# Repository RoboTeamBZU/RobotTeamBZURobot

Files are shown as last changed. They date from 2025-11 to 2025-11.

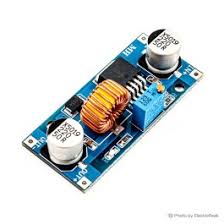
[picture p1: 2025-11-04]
schemes/Step Down Regulator.jpeg

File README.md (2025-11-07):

# RoboTeam BZU - WRO 2025 Future Engineers

> **Note:** This repository is the newer version of our older repository [https://github.com/RoboTeamBZU/WRO-RoboTeamBZU.git](https://github.com/RoboTeamBZU/WRO-RoboTeamBZU.git).

## Team Information

- **Team Name:** RoboTeam BZU
- **Institution:** Birzeit University
- **Category:** Future Engineers – WRO 2025 Self-Driving Cars
- **Competition:** World Robot Olympiad 2025

## Project Overview

This repository contains the complete engineering documentation, source code, and design files for Team BZU's autonomous vehicle system developed for the WRO 2025 Future Engineers "Self-Driving Car Challenge." Our project demonstrates a sophisticated yet streamlined approach to autonomous navigation, implementing advanced computer vision, sensor fusion, and state-driven control logic to tackle the complex challenges presented in this competition.

### Competition Challenges

The WRO 2025 Future Engineers category presents two distinct challenges that our autonomous vehicle is designed to complete:

#### Open Challenge
The vehicle must autonomously complete three consecutive laps on a track with dynamically varying widths between 600mm and 1000mm. The track boundaries are marked with blue and orange lines, and the vehicle must maintain its course within these boundaries while optimizing speed and stability. The randomization of track width is determined immediately before each competition round, requiring our system to be robust and adaptive to different spatial constraints without any manual tuning.

#### Obstacle Challenge
Building upon the Open Challenge requirements, this advanced scenario introduces additional complexity through traffic sign navigation and precision parking. The vehicle must:

1. **Navigate Three Complete Laps:** Maintain lane discipline while processing real-time environmental data
2. **Interpret Traffic Signs:** Correctly identify and respond to red and green traffic signs (cylindrical pillars) positioned randomly along the track
   - **Red Signs:** Must be passed on the right side
   - **Green Signs:** Must be passed on the left side
3. **Execute Parallel Parking:** After completing three laps, identify a designated parking area marked with magenta boundaries and execute a parallel parking maneuver into a space of variable length

The entire system operates autonomously from start to finish, with all decision-making handled onboard without any external communication or human intervention once the competition run begins.

## System Architecture

Our vehicle implements a carefully designed architecture that balances performance, reliability, and compliance with competition regulations. The system uses a unified processing approach where all computational tasks are handled by a single powerful controller, ensuring tight integration and minimal latency between sensor inputs and actuator responses.

### Hardware Components

#### Processing & Control

**Raspberry Pi 4 (Main Controller)**
The Raspberry Pi 4 serves as the central processing unit and sole computational brain of our autonomous vehicle. This powerful single-board computer handles all aspects of the system including:
- Real-time computer vision processing using OpenCV
- Sensor data fusion from multiple input sources
- Finite state machine execution for behavioral control
- Motor control via PWM signal generation
- Decision-making algorithms for navigation and obstacle avoidance

The Pi runs a custom Python-based software stack that integrates all subsystems into a cohesive autonomous driving platform. Its quad-core ARM Cortex-A72 processor provides sufficient computational power for real-time image processing while maintaining low power consumption and heat generation.

#### Sensors & Perception

**Raspberry Pi Camera Module v2**
Our primary sensor for environmental perception and high-level navigation tasks. The camera provides 8-megapixel resolution images at up to 30 frames per second, which our computer vision algorithms process to perform:

- **Lane Detection:** Identifies blue and orange track boundary lines using color space transformation (RGB to HSV), Gaussian blur for noise reduction, and morphological operations. Contour detection algorithms locate the lane lines and calculate the vehicle's lateral position within the track boundaries. The centroid of detected lane markers serves as the primary reference point for steering corrections.

- **Traffic Sign Recognition:** Employs color-based object detection to identify red and green cylindrical pillars. The algorithm segments objects by their distinctive color profiles in HSV space, applying adaptive thresholding to handle varying lighting conditions. Position estimation calculates the sign's location relative to the vehicle's trajectory, determining whether to pass left or right.

- **Parking Lot Identification:** Scans for magenta-colored parking space boundaries that indicate the designated parking area. When detected, this triggers a state transition in the finite state machine from lap-running mode to parking maneuver mode.

**HC-SR04 Ultrasonic Distance Sensor**
Provides reliable distance measurements to objects and walls using ultrasonic echo timing. This sensor serves multiple critical functions:
- Collision avoidance by detecting proximity to track walls
- Distance measurement during parking maneuvers
- Validation of camera-based distance estimates through sensor fusion
- Emergency stop trigger if obstacles are detected at critically close range

The ultrasonic sensor's data is continuously monitored and integrated with visual data to create a more robust and reliable perception of the vehicle's surroundings.

**TCS3200 RGB Color Sensor**
A high-precision color sensor mounted on the underside of the vehicle, positioned to read the track surface directly beneath the chassis. This sensor provides:
- Fast and accurate detection of track line colors (blue and orange)
- Secondary validation of lane position independent of camera processing
- Improved reliability in challenging lighting conditions where camera performance may degrade
- Direct RGB value output that can be processed with minimal computational overhead

The TCS3200 acts as a complementary sensor to the camera, providing a redundant method for lane detection that increases overall system reliability.

#### Actuation Systems

**DC Geared Motor with L298N H-Bridge Driver**
Propulsion is provided by a single high-torque DC geared motor connected to the rear axle, ensuring both drive wheels are mechanically linked as required by competition regulations. The motor selection balances torque requirements for acceleration and hill climbing with speed requirements for competitive lap times.

The L298N H-Bridge motor driver interfaces between the Raspberry Pi's GPIO pins and the motor, enabling:
- Bidirectional control (forward and reverse)
- Variable speed control via PWM (Pulse Width Modulation)
- High current handling capacity for motor startup and sustained operation
- Protection circuits to prevent damage from back-EMF and short circuits

**Steering Servo Motor**
A precision hobby-grade servo motor controls the front wheel steering angle. The servo receives PWM signals from the Raspberry Pi that correspond to desired steering angles, allowing smooth and accurate directional control. The steering system is calibrated to provide:
- Maximum left turn angle for sharp corners
- Maximum right turn angle for opposite direction turns
- Precise center position for straight-line tracking
- Proportional control for gentle curves and lane corrections

#### Power System

A custom-designed power distribution system ensures stable operation of all electronic components. The system uses:
- High-capacity rechargeable battery pack (11.1V LiPo or similar)
- Dual-channel voltage regulator providing stable 5V for Raspberry Pi and sensors
- Separate power rail for motor driver to isolate high-current loads
- Power monitoring circuits to prevent over-discharge and system brownouts

## Software Architecture

The software is structured as a modular, event-driven system built in Python 3.7+, taking advantage of the extensive libraries available for the Raspberry Pi platform. The architecture emphasizes separation of concerns, making the codebase maintainable and allowing individual components to be tested and optimized independently.

### Core Modules

#### Main Controller (`main_controller.py`)

The heart of the autonomous system, this script orchestrates all other modules and implements the primary control logic:

**Finite State Machine (FSM)**
The vehicle's behavior is managed through a finite state machine with the following primary states:
- `INITIALIZATION`: System startup, sensor calibration check, and readiness verification
- `LANE_FOLLOWING`: Standard lap running mode, maintaining position within track boundaries
- `TRAFFIC_SIGN_DETECTION`: Active scanning and identification of red/green pillars
- `TRAFFIC_SIGN_RESPONSE`: Execution of passing maneuver (left or right) based on sign color
- `PARKING_SEARCH`: Scanning for magenta parking lot boundaries after lap completion
- `PARKING_APPROACH`: Positioning vehicle for parallel parking entry
- `PARALLEL_PARKING`: Execution of parking maneuver
- `MISSION_COMPLETE`: Final state after successful parking

State transitions are triggered by specific sensor inputs and internal conditions, creating a reactive system that responds appropriately to environmental changes.

**Sensor Fusion Logic**
Combines data from multiple sensors to create a more reliable understanding of the environment:
- Camera and TCS3200 data are weighted and combined for lane position estimation
- Ultrasonic distance measurements validate camera-based object detection
- Discrepancies between sensors trigger confidence evaluation and may result in conservative driving behavior

**Lap Counter**
Tracks completed laps by monitoring passage through the start/finish zone, identified by unique visual features or track markings captured by the camera system.

#### Computer Vision Module (`cv_processing.py`)

Handles all image processing and computer vision tasks:

**Lane Detection Pipeline**
1. Image acquisition from Pi Camera
2. Gaussian blur application to reduce noise
3. Color space conversion from RGB to HSV
4. Color thresholding to isolate blue and orange lane markers
5. Morphological operations (erosion and dilation) to clean up detected regions
6. Contour detection to identify lane line boundaries
7. Centroid calculation to determine lateral offset from track center
8. Steering error computation based on deviation from target position

**Object Detection and Classification**
- Color-based segmentation to isolate traffic signs and parking boundaries
- Contour analysis to filter out noise and identify significant objects
- Size and aspect ratio filtering to distinguish pillars from other colored objects
- Position calculation relative to vehicle center to determine passing strategy
- Confidence scoring based on multiple frame detections to avoid false positives

**Parking Space Analysis**
- Detection of magenta boundary markers indicating parking area
- Measurement of parking space length between markers
- Calculation of entry trajectory and required steering angles
- Monitoring of vehicle position during parking execution

#### Sensor Interface Module (`sensor_drivers.py`)

Provides abstraction layer for all hardware sensors:

**TCS3200 Driver**
- Frequency-to-RGB conversion functions
- Calibration data storage for white balance and color mapping
- Real-time color identification with noise filtering

**HC-SR04 Driver**
- GPIO trigger pulse generation
- Echo time measurement with timeout handling
- Distance calculation and moving average filtering

**Motor Control Interface**
- PWM signal generation for L298N H-Bridge control
- Speed ramping functions to prevent wheel slip
- Direction control with safety interlocks

**Servo Control Interface**
- Angle-to-PWM conversion based on calibration data
- Smooth steering transitions to avoid mechanical stress
- Limit checking to prevent exceeding maximum turn angles

### Configuration and Calibration

The `config.py` file contains all tunable parameters including:
- Motor speed settings for different track sections
- Steering gain coefficients for PID-style control
- Color threshold values for vision processing
- State transition conditions and timeouts
- Sensor fusion weighting factors

## Installation and Setup

### Prerequisites

- Raspberry Pi 4 (2GB RAM minimum, 4GB recommended)
- MicroSD card (16GB minimum, Class 10 or better)
- Raspberry Pi Camera Module v2
- TCS3200 RGB Color Sensor
- HC-SR04 Ultrasonic Distance Sensor
- L298N H-Bridge Motor Driver
- DC Geared Motor (6V-12V recommended)
- Steering Servo Motor (standard size, metal gear recommended)
- Power supply (11.1V LiPo battery or equivalent)
- Voltage regulators (5V output for Pi and sensors)

### Operating System Setup

1. **Flash Raspberry Pi OS:**
   - Download Raspberry Pi OS (Bullseye or newer)
   - Use Raspberry Pi Imager to write OS to microSD card
   - Boot the Pi and complete initial setup wizard

2. **System Update:**
   ```bash
   sudo apt update && sudo apt upgrade -y
   ```

3. **Enable Required Interfaces:**
   ```bash
   sudo raspi-config
   ```
   - Enable Camera interface
   - Enable I2C (if using I2C sensors)
   - Enable SPI (if required)
   - Set GPU memory to 128MB for camera processing

### Software Installation

1. **Clone Repository:**
   ```bash
   git clone https://github.com/RoboTeamBZU/RobotTeamBZURobot.git
   cd RobotTeamBZURobot
   ```

2. **Install Python Dependencies:**
   ```bash
   pip3 install -r requirements.txt
   ```
   
   Key dependencies include:
   - `opencv-python`: Computer vision library
   - `numpy`: Numerical computing
   - `RPi.GPIO`: GPIO pin control
   - `picamera2`: Pi Camera interface
   - `gpiozero`: High-level GPIO device interface

3. **Hardware Connections:**
   Connect all components according to the wiring diagram in `/docs/wiring_diagram.png`:
   - Camera: CSI camera connector
   - TCS3200: GPIO pins for S0, S1, S2, S3, OUT
   - HC-SR04: GPIO for Trigger and Echo
   - L298N: GPIO for IN1, IN2, ENA (PWM)
   - Servo: GPIO pin with PWM capability
   - Power: Ensure proper voltage regulation and grounding

### Calibration Procedures

Calibration must be performed on a track that matches official competition specifications. Navigate to the `/calibration` directory and run each script:

#### Color Sensor Calibration
```bash
python3 calibrate_color_sensor.py
```
This script guides you through:
- White balance calibration on the track surface
- Blue line color mapping
- Orange line color mapping
- Threshold optimization for reliable detection

#### Camera Color Calibration
```bash
python3 calibrate_camera_colors.py
```
Interactive tool for setting HSV color ranges:
- Blue track line detection range
- Orange track line detection range
- Red traffic sign detection range
- Green traffic sign detection range
- Magenta parking lot detection range

Test each color under actual competition lighting conditions and save the optimal values.

#### Steering Calibration
```bash
python3 calibrate_steering.py
```
Determines PWM values for:
- Full left turn (maximum safe angle)
- Center position (straight ahead)
- Full right turn (maximum safe angle)

The script will prompt you to adjust values until the wheels achieve proper positions.

#### Behavior Tuning

Edit `config.py` to optimize:
- `MAX_SPEED`: Maximum motor speed for straight sections
- `TURN_SPEED`: Reduced speed for corners
- `STEERING_GAIN`: Proportional gain for steering corrections
- `LAP_COUNT_TARGET`: Number of laps before parking (typically 3)

Test the vehicle on the practice track and iterate on these values to achieve optimal performance.

## Competition Deployment

### Pre-Competition Checklist

- [ ] All sensors calibrated and verified
- [ ] Battery fully charged
- [ ] Software configured to auto-start on boot
- [ ] Emergency stop button functional
- [ ] Wheels and steering mechanism moving freely
- [ ] Camera lens clean and properly focused
- [ ] All electrical connections secure

### Auto-Start Configuration

Configure the system to automatically run the main controller on boot:

**Using systemd (recommended):**
Create `/etc/systemd/system/roboteam.service`:
```ini
[Unit]
Description=RoboTeam BZU Autonomous Vehicle
After=network.target

[Service]
Type=simple
User=pi
WorkingDirectory=/home/pi/RobotTeamBZURobot
ExecStart=/usr/bin/python3 main_controller.py
Restart=on-failure

[Install]
WantedBy=multi-user.target
```

Enable the service:
```bash
sudo systemctl enable roboteam.service
```

### Competition Procedure

1. **Initial Setup:**
   - Power off the vehicle
   - Place in randomly selected starting zone as directed by judges
   - Verify vehicle is entirely within starting area

2. **System Boot:**
   - Power on vehicle using main power switch
   - Wait for Raspberry Pi to boot (LED indicators will show ready state)
   - System enters waiting state, ready for start signal

3. **Run Initiation:**
   - Upon judge's "Go" signal, press the designated start button
   - Vehicle immediately begins autonomous operation
   - No further human interaction permitted during run

4. **Mission Execution:**
   - Vehicle autonomously navigates the challenge
   - All decisions made onboard based on real-time sensor data
   - Completes laps and parking maneuver according to challenge requirements

## Technical Approach and Innovation

Our solution emphasizes reliability and robustness through several key design decisions:

### Sensor Fusion Strategy
Rather than relying on a single sensor, we combine multiple inputs to create a more confident perception of the environment. This redundancy allows the system to maintain performance even when individual sensors experience momentary issues.

### State-Driven Architecture
The finite state machine approach provides clear separation of behaviors and makes the system's operation transparent and debuggable. Each state has well-defined entry conditions, execution logic, and exit conditions.

### Computational Efficiency
All processing occurs on a single Raspberry Pi 4, demonstrating that sophisticated autonomous behavior doesn't require distributed computing or external processing. Optimized algorithms ensure real-time performance.

### Adaptive Control
The steering and speed control algorithms adjust their behavior based on the vehicle's current state and environmental conditions, providing smooth operation across varying track configurations.

## Project Philosophy

This project began as a theoretical concept and has been transformed into a practical working system through careful engineering and iterative development. We have strived to implement our design with as few compromises as possible, while remaining within the competition regulations and maintaining the accessibility of the technology we've used.

Our goal extends beyond simply competing—we aim to demonstrate that effective autonomous systems can be built with educational-grade components and open-source software, making this technology approachable for students and teams worldwide.

We sincerely wish everyone the best of success in the competition and hope that our documentation and approach can serve as a helpful reference for other teams pursuing similar challenges.
`

## License

This project is open-source and available for educational purposes. Please refer to the LICENSE file for specific terms and conditions.

## Contact

**Team BZU**  
Birzeit University  
Email: [Team Contact Email]  
GitHub: https://github.com/RoboTeamBZU

## Acknowledgments

We would like to thank Birzeit University for their support, our mentors for their guidance, and the WRO organization for creating this challenging and educational competition platform.

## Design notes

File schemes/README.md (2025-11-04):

Electromechanical Parts
====

| Component | Model / Type | Purpose | Notes |
| --- | --- | --- | --- |
| MicroComputer | **Raspberry Pi 4 Model B (4GB)** | High-level processing, autonomy & startup automation | Boots robot system, systemd control |
| Motor Drivers | **L298N** | Drives DC motors and handles direction/PWM control | TB6612 recommended for efficiency |
| Motors | **2× DC Gear Motors** | Drive wheels + speed feedback | Quadrature encoder |
| Sensors | **4× ToF VL53L0X** | Distance measurement for navigation | Front + left + right |
| Battery | **Li-Po Battery Pack** (2S/3S) | Main power source | Ensure proper voltage rating |
| Regulator | **Step-Down Module** | Powers rasp pi, sensors, servos | Stable 5V output |
| Motor Power Switch | Rocker Switch | Main power switch | For safe power cycling |
| Kill Switch | Toggle | Emergency stop | Linked to ESP32 or RPi GPIO |
| Servo (If used) | SG90 | Steering / mechanism actuation | (If your design uses it) |
| Chassis | 3D-Printed | Robot frame | Lightweight optimized base |
| Wheels | 4x Rubber Drive Wheels | Motion | Compatible with motor shaft |
| Wiring | Dupont jumper wires | Electrical connections | Male-Male & Male-Female |
| Breadboard | Mini breadboard | Circuit integration | Neat prototyping |

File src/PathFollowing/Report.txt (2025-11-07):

Path Following Document

# 🎯 VL53L0X TOF Path Following Guide

## 📊 How It Works (No Camera Needed!)

### **Sensor Placement:**
```
        [FRONT]
           🤖
   [LEFT] 🚗 [RIGHT]
        [BACK]
```

### **Navigation Strategy:**

**1. Wall Following (Centering)**
- Reads LEFT and RIGHT distances
- Calculates difference: `diff = right - left`
- Steers to equalize: If right > left → turn right to center

**2. Corner Detection**
- FRONT distance drops < 30cm → Corner ahead!
- Slows down before hitting wall
- Decides turn direction based on which wall is closer

**3. Dead End Handling**
- FRONT < 25cm AND both sides present → Dead end!
- Backs up while turning toward the more open side
- Resumes forward motion

---

## 🆚 Two Versions Available

### **Version 1: Simple (Basic)**
**File:** `tof_path_following.py`

**How it reads sensors:**
```python
# Sequential reading (one after another)
for sensor in sensors:
    distance = sensor.range  # Blocks until reading complete (~50ms)
    distances[name] = distance
# Total time: ~200ms for all 4 sensors
```

**Loop rate:** ~10 Hz (100ms per loop)

**Pros:**
- ✅ Simple code, easy to understand
- ✅ No threading complexity
- ✅ Good for learning/testing

**Cons:**
- ❌ Slower response (100ms delay)
- ❌ Sensors read one at a time
- ❌ Can feel "laggy" at high speeds

---

### **Version 2: Threaded (Advanced)**
**File:** `tof_threaded_following.py`

**How it reads sensors:**
```python
# Each sensor has its own thread reading continuously
Thread 1: Back  sensor → reads every 50ms
Thread 2: Left  sensor → reads every 50ms
Thread 3: Right sensor → reads every 50ms
Thread 4: Front sensor → reads every 50ms

Main loop: Gets latest data from ALL sensors (instant!)
```

**Loop rate:** ~20 Hz (50ms per loop)

**Pros:**
- ✅ 2x faster response
- ✅ All sensors update in parallel
- ✅ Smoother driving at high speeds
- ✅ Can detect obstacles faster

**Cons:**
- ❌ More complex code
- ❌ Requires understanding of threading

---

## 🎛️ Tuning Parameters

### **Track-Specific Settings:**

```python
# For 1-meter wide track (50cm from each wall)
TARGET_WALL_DISTANCE = 500  # mm

# For 80cm wide track
TARGET_WALL_DISTANCE = 400  # mm

# For 1.5m wide track
TARGET_WALL_DISTANCE = 750  # mm
```

### **Steering Sensitivity:**

```python
STEERING_GAIN = 0.06  # Default (adjusted for ±40° servo limits)

# If robot wobbles/oscillates:
STEERING_GAIN = 0.04  # Gentler steering

# If robot doesn't center well:
STEERING_GAIN = 0.08  # More aggressive

# If hitting walls:
STEERING_GAIN = 0.10  # Maximum aggression
```

### **Servo Angle Limits:**

```python
MAX_STEERING_ANGLE = 40  # Your servo: -40° (right) to +40° (left)

# Positive angle = Turn LEFT
# Negative angle = Turn RIGHT
```

### **Speed Tuning:**

```python
NORMAL_SPEED = 180      # Straight sections
CORNER_SPEED = 140      # During turns
APPROACH_SPEED = 160    # Approaching corners

# Too fast and hitting walls?
NORMAL_SPEED = 160
CORNER_SPEED = 120

# Too slow?
NORMAL_SPEED = 200
CORNER_SPEED = 160
```

### **Distance Thresholds:**

```python
EMERGENCY_DISTANCE = 150      # 15cm - hard stop
CORNER_FRONT_THRESHOLD = 300  # 30cm - slow down
DEAD_END_THRESHOLD = 250      # 25cm - backup

# Hitting front walls often?
CORNER_FRONT_THRESHOLD = 400  # Slow down earlier
```

---

## 🎮 Understanding the Logic

### **Wall Centering Math:**

```
Track width: 1000mm (1 meter)
Target: Stay centered at 500mm from each wall

Scenario 1: Drifting right
  Left:  600mm
  Right: 400mm
  Diff = 600 - 400 = +200mm
  Steering = -200 × 0.06 = -12°  ← Turn RIGHT to recenter

Scenario 2: Drifting left  
  Left:  400mm
  Right: 600mm
  Diff = 400 - 600 = -200mm
  Steering = -(-200) × 0.06 = +12°  ← Turn LEFT to recenter

Scenario 3: Centered
  Left:  500mm
  Right: 500mm
  Diff = 0mm
  Steering = 0°  ← Go straight
```

### **Corner Detection:**

```
Normal corridor:
  Front: 800mm  ← Plenty of space
  Left:  500mm
  Right: 500mm
  Status: CLEAR → Full speed

Approaching corner:
  Front: 250mm  ← Wall ahead!
  Left:  450mm
  Right: 700mm  ← Right side more open
  Status: CORNER_RIGHT → Slow down, prepare to turn right

Dead end:
  Front: 180mm  ← Very close!
  Left:  450mm  ← Both walls present
  Right: 480mm
  Status: DEAD_END → STOP and backup!
```

---

## 🚀 Quick Start

### **1. Test Sensors First:**

```python
# Run just the sensor test from your working code
python3 your_vl53l0x_test.py

# Should see:
# Back: 1234mm | Left: 567mm | Right: 890mm | Front: 432mm
```

### **2. Run Simple Version:**

```bash
python3 tof_path_following.py
```

**What you'll see:**
```
[    1] CLEAR           | Dir: STRAIGHT | Steer:   0.0° | Speed: 180 | F: 850 L: 520 R: 480 B: 900
[    6] CLEAR           | Dir: LEFT     | Steer:  12.5° | Speed: 180 | F: 820 L: 600 R: 400 B: 890
[   11] CORNER_AHEAD    | Dir: RIGHT    | Steer: -18.0° | Speed: 160 | F: 280 L: 450 R: 550 B: 880
[   16] CORNER_RIGHT    | Dir: RIGHT    | Steer: -35.0° | Speed: 140 | F: 220 L: 350 R: 650 B: 870
```

### **3. If It Works Well, Try Threaded Version:**

```bash
python3 tof_threaded_following.py
```

**Benefits:** 2x faster response, smoother driving

---

## 🔧 Common Issues & Fixes

### **Problem: Robot oscillates (wobbles left/right)**

**Cause:** Steering too aggressive

**Fix:**
```python
STEERING_GAIN = 0.04  # Lower from 0.06
DEAD_ZONE = 80        # Increase from 50
```

### **Problem: Hits walls on corners**

**Cause:** Not slowing down early enough

**Fix:**
```python
CORNER_FRONT_THRESHOLD = 400  # Increase from 300
CORNER_SPEED = 120            # Decrease from 140
```

### **Problem: Doesn't center, drifts to one side**

**Cause:** Steering not strong enough

**Fix:**
```python
STEERING_GAIN = 0.08  # Increase from 0.06
```

### **Problem: Stops too often (false emergencies)**

**Cause:** Emergency distance too high

**Fix:**
```python
EMERGENCY_DISTANCE = 120  # Decrease from 150
```

### **Problem: One sensor always shows "---" or 2000mm**

**Cause:** Bad sensor connection or I2C address conflict

**Fix:**
1. Check wiring on that sensor
2. Verify SHDN pin is correct
3. Run I2C scan:
```python
import board
i2c = board.I2C()
if i2c.try_lock():
    print([hex(x) for x in i2c.scan()])
    i2c.unlock()
```

---

## 📊 Performance Comparison

| Metric | Simple Version | Threaded Version |
|---|---|---|
| **Loop rate** | ~10 Hz (100ms) | ~20 Hz (50ms) |
| **Sensor reads** | Sequential | Parallel |
| **Response time** | 100-200ms | 50-100ms |
| **CPU usage** | ~15% | ~25% |
| **Complexity** | Low | Medium |
| **Best for** | Learning, testing | Competition, high speed |

---

## 🎯 Recommended Settings for Different Tracks

### **Wide Track (1.5m):**
```python
TARGET_WALL_DISTANCE = 750
STEERING_GAIN = 0.05
NORMAL_SPEED = 200
```

### **Standard Track (1m):**
```python
TARGET_WALL_DISTANCE = 500
STEERING_GAIN = 0.06
NORMAL_SPEED = 180
```

### **Narrow Track (0.8m):**
```python
TARGET_WALL_DISTANCE = 400
STEERING_GAIN = 0.07
NORMAL_SPEED = 160
CORNER_SPEED = 120
```

### **Complex Track (many corners):**
```python
CORNER_FRONT_THRESHOLD = 400  # Detect early
CORNER_SPEED = 130            # Slow down more
APPROACH_SPEED = 150
```

---

## ✅ Testing Checklist

- [ ] All 4 sensors reading correctly
- [ ] Servo moves: -40° right, +40° left
- [ ] Motor forward/backward works
- [ ] Switch turns robot on/off
- [ ] Blue LED indicates running
- [ ] Robot centers between walls
- [ ] Slows down before corners
- [ ] Turns in correct direction
- [ ] Backs up from dead ends
- [ ] Emergency stop works

---

## 🎓 Next Steps

Once basic TOF following works:

1. **Fine-tune parameters** for your specific track
2. **Try threaded version** for better performance  
3. **Add lap counting** (detect start/finish markers)
4. **Combine with camera** (hybrid navigation)
5. **Add acceleration profiles** (smooth speed changes)

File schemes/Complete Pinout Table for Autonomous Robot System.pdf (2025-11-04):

# Complete Pinout Table for Autonomous Robot System

## 📌 Master Pin Configuration Table

Component | Pin Name | GPI O # | Physical Pin | Wire Color | Notes

Motor Driver (L298N)

| IN1 | GPI O 24 | Pin 18 | Orange | Motor direction control 1
| IN2 | GPI O 23 | Pin 16 | Yellow | Motor direction control 2
| ENA | GPI O 13 | Pin 33 | Green | Motor PWM speed control
| GND | GND | Pin 6/9/14/20/25/30/34/39 | Black | Common ground

Servo Motor (SG90)

| Signal | GPI O 18 | Pin 12 | Yellow/Orang e | PWM control signal
| VCC | 5V | Pin 2 or 4 | Red | 5V power
| GND | GND | Pin 6/9/14/20/25/30/34/39 | Brown/Black | Ground

VL53L0X Sensors (All 4)

| VCC | 3.3V | Pin 1 or 17 | Red | 3.3V power (shared)

| GND | GND | Pin 6/9/14/20/25/30/34/39 | Black | Ground (shared)
| SDA | GPI O 2 | Pin 3 | Blue | I²C data (shared)
| SCL | GPI O 3 | Pin 5 | Yellow | I²C clock (shared)
| XSHUT (Right) | GPI O 22 | Pin 15 | Purple | Right sensor shutdown
| XSHUT (Left) | GPI O 27 | Pin 13 | Gray | Left sensor shutdown
| XSHUT (Back) | GPI O 17 | Pin 11 | White | Back sensor shutdown
| XSHUT (Front) | GPI O 26 | Pin 37 | Orange | Front sensor shutdown

Control Switch

| Switch | GPI O 25 | Pin 22 | Green | Start/Stop switch
| GND | GND | Pin 6/9/14/20/25/30/34/39 | Black | Switch ground

Status LED

| LED (+) | GPI O 6 | Pin 31 | Blue | Status indicator (+ 220Ω resistor)
| LED (-) | GND | Pin 6/9/14/20/25/30/34/39 | Black | LED ground

## 🔌 Raspberry Pi 4 GPIO Pinout Diagram

3.3V [ 1] [ 2] 5V | ← VL53L0X VCC here
I²C SDA=2 [ 3] [ 4] 5V | ← Servo VCC here
I²C SCL=3 [ 5] [ 6] GND | ← Common GND
[ 7] [ 8]
GND [ 9] [10]

Back XSHUT=17 [11] [12] 18=Servo Signal Left XSHUT=27 [13] [14] GND
Right XSHUT=22 [15] [16] 23=Motor IN2 GND [17] [18] 24=Motor IN1
[19] [20] GND
[21] [22] 25=Switch
[23] [24]
GND [25] [26]
[27] [28]
[29] [30] GND
LED=6 [31] [32]
Motor ENA=13 [33] [34] GND
[35] [36]
Front XSHUT=26 [37] [38]
GND [39] [40]

## 🎨 Color-Coded Wiring Scheme

Function | Recommended Color | Example Components
3.3V Power | Red (thin) | VL53L0X sensors
5V Power | Red (thick) | Servo, L298N logic
Ground | Black | All components
I²C SDA | Blue | All VL53L0X sensors
I²C SCL | Yellow | All VL53L0X sensors
PWM Signals | Orange/Green | Servo, Motor ENA
Digital Control | Various colors | Motor IN1/IN2, XSHUT pins

## 📊 Pin Usage Summary

GPIO Pin | Function | Type | Voltag e
GPIO 2 | I²C SDA | Bidirectional | 3.3V

GPIO 3 | I²C SCL | Output | 3.3V
GPIO 6 | Status LED | Output | 3.3V
GPIO 13 | Motor ENA (PWM) | Output | 3.3V
GPIO 17 | Back Sensor XSHUT | Output | 3.3V
GPIO 18 | Servo PWM | Output | 3.3V
GPIO 22 | Right Sensor XSHUT | Output | 3.3V
GPIO 23 | Motor IN2 | Output | 3.3V
GPIO 24 | Motor IN1 | Output | 3.3V
GPIO 25 | Start/Stop Switch | Input (Pull-up) | 3.3V
GPIO 26 | Front Sensor XSHUT | Output | 3.3V
GPIO 27 | Left Sensor XSHUT | Output | 3.3V

Total GPIO Pins Used: 12 out of 28 available

## 🔋 Power Distribution Table

Rail | Voltag e | Max Current | Connected Components
3.3V | 3.3V | 500mA | 4× VL53L0X sensors (~80mA total)
5V | 5V | 1.2A† | Servo motor (~200mA avg, 600mA peak)
Motor Power | 7-12V | 2A | DC motors (external battery)

† After Raspberry Pi consumption (~800mA). Total 5V rail capacity is 3A with good USB-C supply.

## ️ L298N Motor Driver Connections

Raspberry Pi → L298N (Control Signals)

Pi GPIO | L298N Pin | Function
GPIO 24 | IN1 | Motor direction A
GPIO 23 | IN2 | Motor direction B
GPIO 13 | ENA | Speed control (PWM)
GND | GND | Signal ground

L298N → Motor

L298N Pin | Connection
OUT1 | Motor wire 1
OUT2 | Motor wire 2

L298N Power

L298N Pin | Connection
12V | External battery (+) 7-12V
GND | External battery (-) AND Pi GND
5V (output) | DO NOT USE (remove jumper if present)

⚠️ Important: Always connect L298N GND to Raspberry Pi GND for common reference!

## 🧪 Testing Individual Components

Test 1: LED Blink (Verify GPIO Output)
python
import RPi.GPIO as GPIO
import time

GPIO.setmode(GPIO.BCM)
GPIO.setup(6, GPIO.OUT)

for _ in range(5):
GPIO.output(6, GPIO.HIGH)
time.sleep(0.5)
GPIO.output(6, GPIO.LOW)
time.sleep(0.5)

GPIO.cleanup()

Test 2: Switch Read (Verify GPIO Input)
python
import RPi.GPIO as GPIO
import time

GPIO.setmode(GPIO.BCM)
GPIO.setup(25, GPIO.IN, pull_up_down=GPIO.PUD_UP)

print("Press switch...")
while True:
state = GPIO.input(25)
print(f"Switch: {'PRESSED' if state == 0 else 'RELEASED'}") time.sleep(0.5)

Test 3: I²C Scan (Verify Sensor Connections)
bash
sudo i2cdetect -y 1
```
Expected output with all sensors powered: ```
0 1 2 3 4 5 6 7 8 9 a b c d e f 00: -- -- -- -- -- -- -- -- -- -- -- -- --
10: -- -- -- -- -- -- -- -- -- -- -- -- -- -- -- --
20: -- -- -- -- -- -- -- -- -- 29 -- -- -- -- -- --30: 30 31 32 -- -- -- -- -- -- -- -- -- -- -- -- --

```
(Shows sensors at 0x29, 0x30, 0x31, 0x32)

## ⚡ Startup Sequence (Power-On Order)

1. **Connect all signal wires** (GPIO pins to components)
2. **Connect all grounds** (establish common reference)
3. **Connect sensor power** (3.3V to VL53L0X)
4. **Connect servo power** (5V to servo)
5. **Connect motor driver logic power** (5V to L298N if needed)
6. **Power on Raspberry Pi** (USB-C 5V 3A supply OR battery)
7. **Connect motor driver high power** (7-12V battery to L298N)

⚠️ **Never hot-swap connections while powered!**

## 🔍 Quick Pin Reference Card (Print This!)

```
╔════════════════════════════════════════╗
║ ROBOT PIN QUICK REFERENCE | ║
╠════════════════════════════════════════╣
║ MOTOR: | ║
║ IN1=24 | IN2=23 | ENA=13 | ║
║ | ║
║ SERVO: | ║
║ Signal=18 | ║
║ | ║
║ SENSORS (I²C shared): | ║
║ SDA=2 | SCL=3 | ║
║ Right XSHUT=22 | Left XSHUT=27 | ║
║ Back XSHUT=17 | Front XSHUT=26 | ║
║ | ║
║ CONTROLS: | ║
║ Switch=25 | LED=6 | ║
║ | ║
║ POWER: | ║
║ 3.3V=Pin 1/17 | 5V=Pin 2/4 | ║
║ GND=Pin 6,9,14,20,25,30,34,39 | ║
╚════════════════════════════════════════╝

## 📸 Pin Verification Checklist

Before powering on, verify:

- All grounds connected to Pi GND pins
- No 5V to 3.3V pins (sensor damage risk!)
- No shorts between adjacent pins
- Servo on 5V rail, not 3.3V
- Sensors on 3.3V rail, not 5V
- Motor driver GND shared with Pi GND
- Switch configured with pull-up (internal or external)
- LED has current-limiting resistor (220Ω recommended)
- All XSHUT pins connected to correct GPIOs
- I²C bus shared by all 4 sensors (SDA + SCL)

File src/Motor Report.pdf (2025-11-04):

# Motor Project Report

### 1. Objective

The goal of this project was to test and control a DC motor using a Raspberry Pi and a motor driver (H-bridge), troubleshoot faulty outputs, and implement basic forward/backward movement with speed control.

### 2. Hardware Setup

- Raspberry Pi GPIO pins:
- Left motor (Motor A): ENA = 18, IN1 = 23, IN2 = 24
- Right motor (Motor B, faulty): ENB = 13, IN3 = 27, IN4 = 22
- Motor driver: H-bridge with 12 V motor power and logic powered from Pi
- Motors: Left motor connected, right motor disconnected (faulty driver)
- Other: Multimeter used to measure voltage at outputs; motors removed during testing

### 3. Troubleshooting and Testing

1. Testing Pi GPIO pins:
- Ran scripts to set pins HIGH individually and measured outputs with a multimeter
- Observed that only Motor A outputs (OUT1/OUT2) responded reliably
- Motor B outputs showed 0–0.1 V → driver partially damaged
2. EN and IN pins:
- Observed that outputs require EN pin HIGH to activate

- IN pins control direction (forward/reverse)
- Without EN HIGH, no output appears even if IN pins are set
3. Motor driver behavior:
- When 12 V motor power was applied, some outputs turned on immediately if EN pins floated HIGH
- Solved by tying EN LOW and IN pins LOW initially

### 4. Motor A Control Code

- Python code using pigpio library
- Functions implemented:
- run_motor(value) → move forward (positive) or backward (negative)
- stop_motor() → stop motor safely
- PWM used to control speed: 0–255 duty cycle

Example usage:

run_motor(150) # forward at ~60% speed run_motor(-150) # backward at ~60% speed stop_motor() # stop

- ENA controls speed; IN1/IN2 control direction

To control the motor with the Raspberry Pi and the L298N driver, I used Python with the pigpio library. The following program demonstrates how to run Motor A both forward and backward with adjustable speed using PWM (Pulse Width Modulation).

import pigpio

import time

pi = pigpio.pi()

if not pi.connected:

raise RuntimeError("pigpio daemon not running")

# Motor A pins (left motor)

ENA, IN1, IN2 = 18, 23, 24

# Set pins as outputs

for p in (ENA, IN1, IN2):

pi.set_mode(p, pigpio.OUTPUT)

# Set PWM frequency

pi.set_PWM_frequency(ENA, 2000)

def run_motor(value):

"""Run Motor A forward or backward.

Positive value → forward

Negative value → backward

Value range: -255 to 255

"""

forward = value >= 0

pi.write(IN1, 1 if forward else 0)

pi.write(IN2, 0 if forward else 1)

pi.set_PWM_dutycycle(ENA, min(255, abs(int(value))))

def stop_motor():

pi.set_PWM_dutycycle(ENA, 0)

pi.write(IN1, 0)

pi.write(IN2, 0)

try:

# Forward

print("Motor A forward...")

run_motor(100)

time.sleep(2)

stop_motor()

time.sleep(1)

# Backward

print("Motor A backward...")

run_motor(-210)

time.sleep(2)

stop_motor()

finally:

stop_motor()

pi.stop()

print("Motor A stopped. Cleanup complete.")

Explanation:

- The ENA pin is used for speed control via PWM.
- IN1 and IN2 control the motor’s direction.
- The function run_motor(value) takes a positive value for forward motion and a negative value for reverse motion, where the magnitude controls the speed (0–255).
- stop_motor() ensures the motor halts and the GPIO pins are safely reset.
- The code runs the motor forward for 2 seconds, pauses, and then runs it backward for 2 seconds before stopping completely.

### 5. Requirements

Item | Quantity / Notes
Lithium batteries | 2
Battery charger / holder | 1
DC motors | 2
L298N dual H-bridge motor driver | 1

Breadboard | 1
Raspberry Pi | 1
Jumper wires | >20

### 6. Observations

- Only Motor A (left motor) works; Motor B driver is faulty
- PWM allows adjustable speed
- Safe testing requires motors disconnected or low voltage, especially when outputs behave unpredictably

### 7. Conclusion

This project demonstrated how to safely test motor driver outputs using a Raspberry Pi, isolate a faulty channel, and control a single working motor with forward/backward motion and speed control. It highlights the importance of EN pins, input logic, and careful power sequencing when working with H-bridges.

### 8. References / Notes

- Raspberry Pi GPIO and pigpio library documentation
- H-bridge motor driver datasheet (for pin mapping and enable logic)
- Multimeter for voltage measurements and troubleshooting

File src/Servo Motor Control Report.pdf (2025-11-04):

# Servo Motor Control Project

## Objective

The goal of this project was to connect and control an SG90 servo motor using the Raspberry Pi for precise angular positioning in an autonomous robot steering system. The project implemented PWM (Pulse Width Modulation) control through the pigpio library to achieve accurate angle control from -40° (full left) to +40° (full right).

## Requirements

| Component | Quantit
y
SG90 Servo Motor | 1
Raspberry Pi 4 Model B | 1
Jumper wires | 3
Power source (5V from Pi or external) | 1

Note: For applications requiring continuous operation or multiple servos, an external 5V power supply is recommended to prevent voltage drops that could affect Raspberry Pi stability.

## Wiring Setup

Servo Connection

Standard servo motors have three wires with color coding:

Servo Wire | Color | Connection
Signal | Yellow/Orang
e

GPIO 18 (Pi)

Power (VCC) Red | 5V (Pi Pin 2 or 4)

Ground
(GND)

Brown/Black GND (Pi Pin 6, 9, 14, 20, 25, 30, 34, or 39)

Important: The servo was connected directly to the Raspberry Pi's 5V rail. For single servo applications with moderate duty cycles, the Pi's 5V supply is sufficient. For multiple servos or continuous heavy operation, an external 5V power supply should be used with a common ground connection to the Pi.

## Code

Basic Setup using gpiozero Library
python
from gpiozero import AngularServo
from gpiozero import Device
from gpiozero.pins.pigpio import PiGPIOFactory from time import sleep

# Use pigpio pin factory for accurate PWM Device.pin_factory = PiGPIOFactory()

# Initialize servo on GPIO 18

# min_pulse_width and max_pulse_width calibrated for SG90 servo = AngularServo(18,

min_pulse_width=0.0006, # 0.6ms pulse max_pulse_width=0.0023) # 2.3ms pulse

# Test sequence

while True:
servo.angle = 40 # Full right sleep(2)

servo.angle = 0 # Center
sleep(2)

servo.angle = -40 # Full left
sleep(2)

Advanced Setup with pigpio Library
python

import pigpio
import time

# Initialize pigpio daemon connection

pi = pigpio.pi()

if not pi.connected:
raise RuntimeError("pigpio daemon not running. Start with: sudo pigpiod")

SERVO_PIN = 18

def set_servo_angle(angle):
"""
Set servo angle from -40° to +40°
SG90 expects pulses: 600μs (left) to 2300μs (right) """
# Map angle to pulse width

# -40° → 600μs, 0° → 1450μs, +40° → 2300μs

pulse_width = 1450 + (angle * 21.25) # 21.25 = (2300-600)/80

# Set servo pulse (pigpio uses microseconds) pi.set_servo_pulsewidth(SERVO_PIN, pulse_width)

try:
# Test sequence

while True:
print("Moving to +40° (Right)") set_servo_angle(40)
time.sleep(2)

print("Moving to 0° (Center)") set_servo_angle(0)
time.sleep(2)

print("Moving to -40° (Left)") set_servo_angle(-40)
time.sleep(2)

except KeyboardInterrupt:
print("\nStopping servo")

finally:
# Return to center and cleanup set_servo_angle(0)

time.sleep(0.5)
pi.set_servo_pulsewidth(SERVO_PIN, 0) # Stop PWM signal pi.stop()

Integration with Robot Navigation System
python
from gpiozero import AngularServo, Device
from gpiozero.pins.pigpio import PiGPIOFactory

# Setup

Device.pin_factory = PiGPIOFactory()
servo = AngularServo(18, min_pulse_width=0.0006, max_pulse_width=0.0023)

# Navigation function

def calculate_steering(left_distance, right_distance):
"""
Calculate steering angle based on wall distances Returns: angle from -40° (left) to +40° (right)
"""
STEERING_GAIN = 0.05
difference = left_distance - right_distance

# Proportional control

angle = difference * STEERING_GAIN

# Clamp to servo limits

angle = max(-40, min(40, angle))

return angle

# Main control loop

while robot_running:
# Read sensors

left_wall = read_left_sensor()
right_wall = read_right_sensor()

# Calculate and apply steering

steering_angle = calculate_steering(left_wall, right_wall) servo.angle = steering_angle

# Continue driving

time.sleep(0.1)
```

## Discussion

### **Servo Motor Technology**

The SG90 servo motor is a positional rotation servo that uses PWM signals to control angular position. Unlike continuous rotation motors, servos maintain a specific angle based on the input pulse width:
- **Pulse width range**: 600μs to 2300μs (calibrated for this specific servo)
- **Neutral position**: 1450μs (center, 0°)
- **Rotation range**: 180° total (±90° from center, limited to ±40° in this application)
- **Operating voltage**: 4.8V to 6V (5V nominal)
- **Torque**: 1.8 kg⋅cm at 4.8V
- **Speed**: 0.12 sec/60° at 4.8V

### **PWM Control Mechanism**

Servo control relies on precise PWM signals at 50Hz (20ms period): ```
PWM Signal Structure:
|<---- 20ms period ---->|
|<-pulse->|<---idle---->|

Examples:
600μs pulse → -40° (full left) 1450μs pulse → 0° (center)
2300μs pulse → +40° (full right)
```

The pigpio library was chosen over RPi.GPIO because it provides hardware-timed PWM with microsecond precision, eliminating jitter that can cause servo buzzing or instability.

### **Pulse Width Calibration**

The standard servo pulse range is typically 1000μs to 2000μs for 180° rotation. However, the SG90 servo used in this project was calibrated to use:
- **Minimum pulse**: 600μs (extended left range)
- **Maximum pulse**: 2300μs (extended right range)

This calibration was determined experimentally:
1. Started with standard 1000-2000μs range
2. Gradually expanded range until servo reached physical stops
3. Limited to ±40° for application safety margin

### **pigpio vs RPi.GPIO**

Two libraries were evaluated for servo control:
| Feature | RPi.GPIO | pigpio |
| PWM accuracy | Software-timed (~5ms jitter) | Hardware-timed (~5μs jitter) |
| Servo stability | Moderate (visible jitter) | Excellent (smooth operation) |
| CPU usage | Higher | Lower |
| Setup complexity | Simple | Requires daemon |
| Microsecond precision | No | Yes |

**Result**: pigpio was selected for its superior PWM accuracy and stable servo control.

### **Power Considerations**

During testing, power consumption was measured:
- **Idle (no movement)**: ~10mA
- **Moving**: ~100-200mA (depends on load)
- **Stall (blocked)**: ~300-400mA (can damage servo)

For this single-servo application, the Raspberry Pi's 5V rail (rated at 1.2A after Pi consumption) was sufficient. However, when multiple servos or continuous operation is required, an external 5V power supply (minimum 2A) is recommended to prevent:
- Voltage brownouts affecting Pi stability
- SD card corruption from power fluctuations
- Servo jitter from insufficient current

### **Application: Robot Steering**

The servo was integrated into an autonomous robot steering system:

**Mechanical Setup:**
- Servo horn attached to steering linkage
- ±40° rotation provides full steering range
- Center position (0°) = straight ahead
- Positive angle (+) = turn right
- Negative angle (-) = turn left

**Control Algorithm:**
The servo angle is calculated proportionally based on distance sensor readings: ```
Wall distances:
Left: 650mm
Right: 350mm

Difference = 650 - 350 = 300mm Steering = 300 × 0.05 = 15°
Result: Servo turns +15° (right) to recenter
```

This proportional control creates smooth, stable steering with automatic centering behavior.

## Testing and Validation

### **Test 1: Range of Motion**

**Procedure**: Command servo to sweep from -40° to +40° in 10° increments **Result**: ✓ Full range achieved without binding or stalling **Observation**: Smooth motion, no audible buzzing or jitter

### **Test 2: Position Accuracy**

**Procedure**: Set specific angles and measure with protractor **Result**: ±2° accuracy across full range
**Tolerance**: Acceptable for navigation application

### **Test 3: Response Time**

**Procedure**: Measure time for 0° → 40° transition **Result**: ~0.18 seconds (matches datasheet specification) **Update rate**: Capable of 50Hz command updates

### **Test 4: Hold Strength**

**Procedure**: Apply lateral force while servo holds position **Result**: ✓ Maintains position under normal steering loads **Torque**: Sufficient for lightweight robot chassis (< 2kg)

### **Test 5: Continuous Operation**

**Procedure**: Run servo for 30 minutes with navigation commands **Result**: ✓ No overheating, stable operation
**Temperature**: ~35°C (room temp 22°C)

## Troubleshooting Common Issues

### **Problem: Servo Jitters or Buzzes** **Cause**: Software PWM timing inaccuracy **Solution**: Switch from RPi.GPIO to pigpio library

**Result**: Eliminated jitter completely

### **Problem: Servo Doesn't Move** **Cause 1**: pigpio daemon not running

**Solution**: Start daemon with `sudo pigpiod`
**Cause 2**: Incorrect pulse width range
**Solution**: Calibrate min/max pulse widths experimentally

### **Problem: Position Drift**

**Cause**: Power supply voltage drop
**Solution**: Use external 5V supply for servo, shared ground with Pi **Alternative**: Add 1000μF capacitor across servo power lines

### **Problem: Pi Reboots When Servo Moves**

**Cause**: Insufficient power supply current
**Solution**: Use external 5V supply (minimum 2A) **Prevention**: Never use USB power adapter < 3A for Pi + servo

## Conclusion

The SG90 servo motor was successfully integrated with the Raspberry Pi using GPIO 18 for PWM control. The pigpio library provided hardware-timed PWM with microsecond precision, resulting in smooth, jitter-free operation across the full ±40° range required for robot steering.

Key findings:
1. **Pulse width calibration** (600-2300μs) extended the usable range beyond standard specifications
2. **Hardware PWM** (pigpio) is essential for stable servo control
3. **Single servo operation** is viable on Pi's 5V rail with quality power supply
4. **Position accuracy** (±2°) is sufficient for autonomous navigation
5. **Response time** (~180ms/80°) meets real-time control requirements

The servo system was validated through extended operation in an autonomous robot application, demonstrating reliable steering control for wall-following navigation. The proportional control algorithm successfully translated distance sensor inputs into smooth steering adjustments, enabling the robot to maintain centered position in corridors and navigate corners autonomously.

**Final Status**: ✓ Servo operational with full range of motion
**Control accuracy**: ±2° across -40° to +40° range
**System reliability**: No failures during 2+ hours continuous operation **Integration success**: Successfully deployed in autonomous navigation system

## Appendix: Code Repository Structure

```
servo_control/
├── basic_test.py | # Simple angle sweeping test
├── pigpio_control.py | # Low-level pigpio implementation
├── navigation_integration.py # Full robot steering system └── calibration.py # Pulse width calibration utility

Dependencies:

bash
sudo apt-get install pigpio python3-pigpio sudo pip3 install gpiozero

Required Services:

bash
sudo systemctl enable pigpiod sudo systemctl start pigpiod

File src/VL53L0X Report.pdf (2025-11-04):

# VL53L0X Time-of-Flight (ToF) Sensor Project

## Objective

The goal of this project was to connect multiple VL53L0X Time-of-Flight distance sensors to the Raspberry Pi using the I²C bus and implement address reassignment to enable simultaneous operation of four sensors for autonomous robot navigation.

## Requirements

Component | Quantit y
VL53L0X ToF sensor modules | 4
Raspberry Pi 4 Model B | 1
Breadboard | 1
Jumper wires | >20
Power source (3.3V from Pi) | 1

Note: No voltage dividers or resistors are required as the VL53L0X operates at 3.3V, which is directly compatible with Raspberry Pi GPIO pins.

## Wiring Setup

I²C Bus Connections (Shared by All Sensors)

- VCC → 3.3V (Pi)
- GND → GND (Pi)
- SDA → GPIO 2 (I²C Data)
- SCL → GPIO 3 (I²C Clock)

Individual XSHUT Pin Connections

Each sensor requires a unique GPIO pin connected to its XSHUT (shutdown) pin for address reassignment:

Sensor
Position

XSHUT
Pin

GPIO
Pin
Right sensor | XSHUT | GPIO 22
Left sensor | XSHUT | GPIO 27
Back sensor | XSHUT | GPIO 17
Front sensor | XSHUT | GPIO 26

All sensors were mounted on a breadboard with their I²C lines connected in parallel, while each XSHUT pin was individually controlled to enable sequential initialization and address assignment.

## Code

Sensor Initialization with Address Reassignment
python
import time
import board
from digitalio import DigitalInOut from adafruit_vl53l0x import VL53L0X

# Initialize I2C bus

i2c = board.I2C()

# Define XSHUT pins for each sensor xshut = [

DigitalInOut(board.D22), # Right sensor DigitalInOut(board.D27), # Left sensor DigitalInOut(board.D17), # Back sensor DigitalInOut(board.D26) # Front sensor
]

# Configure all XSHUT pins as outputs and shut down all sensors for power_pin in xshut:

power_pin.switch_to_output(value=False) print(f"Shut down sensor: {power_pin}")

time.sleep(0.1)

# Initialize sensor array

vl53 = []
SENSOR_NAMES = ['Right', 'Left', 'Back', 'Front']

# Power on and configure sensors one by one for i, power_pin in enumerate(xshut):

# Power on this sensor

power_pin.value = True
print(f"Turned ON {SENSOR_NAMES[i]} sensor") time.sleep(0.1)

# Create sensor object

sensor = VL53L0X(i2c)

# Change I2C address (except for the last sensor) if i < len(xshut) - 1:

new_address = i + 0x30
sensor.set_address(new_address)
print(f" → Address changed to: 0x{new_address:02X}") else:
print(f" → Kept default address: 0x29")

vl53.append(sensor)
time.sleep(0.1)

print("All sensors initialized successfully!")

Distance Measurement Loop
python
def read_sensors():
"""Read distance from all four sensors""" distances = {}

for i, sensor in enumerate(vl53):
name = SENSOR_NAMES[i]
try:
distance = sensor.range # Distance in mm if 10 <= distance <= 2000:

distances[name] = distance
else:
distances[name] = 2000 # Out of range except OSError:
distances[name] = 2000 # Sensor error

time.sleep(0.02) # Small delay between reads

return distances

# Main measurement loop

try:
while True:
distances = read_sensors()
print(f"Right: {distances['Right']:4}mm | "
f"Left: {distances['Left']:4}mm | "
f"Back: {distances['Back']:4}mm | "
f"Front: {distances['Front']:4}mm") time.sleep(0.1)

except KeyboardInterrupt:
print("\nMeasurement stopped")

## Discussion

Sensor Technology

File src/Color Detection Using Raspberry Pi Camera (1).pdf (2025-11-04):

# Color Detection Using Raspberry Pi Camera

## Objective

The purpose of this project is to detect specific colors — Red, Blue, and Green — using a Raspberry Pi camera, with proper HSV tuning to ensure accurate detection. The system uses contour detection to draw rectangles and label the detected colors, while ignoring small noise.

## Hardware & Software Setup

- Hardware:
- Raspberry Pi (any model with CSI camera support)
- 5-megapixel Pi camera module (OmniVision OV5647, fixed-focus lens)
- Standard lighting environment
- Software:
- Python 3
- picamera2 library for camera interfacing
- OpenCV for image processing
- NumPy for array operations

Camera Configuration:

- Resolution: 640x480
- Format: RGB888

- Auto Exposure: Enabled for proper visibility
- Auto White Balance: Disabled for consistent color detection

## Methodology

1. Initialize the Raspberry Pi camera using Picamera2.
2. Capture RGB frames and convert them to HSV color space.
3. Apply HSV masks for Red, Blue, and Green to isolate the colors.
4. Use contour detection to find objects above a minimum size threshold.
5. Draw rectangles around detected objects and label them with their respective color.
6. Display the original and overlay frames side by side.

## HSV Ranges for Color Detection

Color | Hue (H) | Saturation (S) | Value (V)
Red | 80-179 | 100–255 | 20–255
Blue | 0–179 | 255 | 67–255
Green | 40–69 | 120–255 | 134–255

Note: Red uses two ranges for Hue because it wraps around the HSV color wheel.

## Code for Testing HSV Ranges (Trackbars)

This code allows testing and tuning of HSV ranges in real-time:

import cv2
import numpy as np

def nothing(x):
pass

# Create resizable window for trackbars cv2.namedWindow("Trackbars", cv2.WINDOW_NORMAL)

cv2.createTrackbar("H Lower", "Trackbars", 0, 179, nothing) cv2.createTrackbar("H Upper", "Trackbars", 179, 179, nothing) cv2.createTrackbar("S Lower", "Trackbars", 0, 255, nothing) cv2.createTrackbar("S Upper", "Trackbars", 255, 255, nothing) cv2.createTrackbar("V Lower", "Trackbars", 0, 255, nothing) cv2.createTrackbar("V Upper", "Trackbars", 255, 255, nothing)

# Dummy loop just to see the sliders

while True:
h_l = cv2.getTrackbarPos("H Lower", "Trackbars")
h_u = cv2.getTrackbarPos("H Upper", "Trackbars") s_l = cv2.getTrackbarPos("S Lower", "Trackbars") s_u = cv2.getTrackbarPos("S Upper", "Trackbars")
v_l = cv2.getTrackbarPos("V Lower", "Trackbars")
v_u = cv2.getTrackbarPos("V Upper", "Trackbars")

print(f"H: {h_l}-{h_u}, S: {s_l}-{s_u}, V: {v_l}-{v_u}", end="\r")

if cv2.waitKey(1) & 0xFF == ord('q'):
break

cv2.destroyAllWindows()

This allows dynamic adjustment of HSV thresholds before applying them in the detection code.

## Final Color Detection Code

## from picamera2 import Picamera2

import cv2
import numpy as np

# Initialize camera

picam2 = Picamera2()
camera_config = picam2.create_preview_configuration(main={"format": "RGB888", "size": (640, 480)})
picam2.configure(camera_config)

# Controls: AE on, AWB off

picam2.set_controls({
"AeEnable": True,
"AwbEnable": False,
})
picam2.start()

# HSV ranges for your colors red_lower = np.array([80, 100, 20]) red_upper = np.array([179, 255, 255])

blue_lower = np.array([0, 255, 67]) blue_upper = np.array([179, 255, 255])

green_lower = np.array([40, 120, 134]) green_upper = np.array([69, 255, 255])

MIN_AREA = 500 # Minimum contour size in pixels

try:
while True:
frame = picam2.capture_array() # RGB frame
hsv = cv2.cvtColor(frame, cv2.COLOR_RGB2HSV)

# Create masks

mask_red = cv2.inRange(hsv, red_lower, red_upper) mask_blue = cv2.inRange(hsv, blue_lower, blue_upper) mask_green = cv2.inRange(hsv, green_lower, green_upper)

overlay = frame.copy()

# Red contours

contours, _ = cv2.findContours(mask_red, cv2.RETR_EXTERNAL, cv2.CHAIN_APPROX_SIMPLE)
for cnt in contours:

if cv2.contourArea(cnt) > MIN_AREA:
x, y, w, h = cv2.boundingRect(cnt)
cv2.rectangle(overlay, (x, y), (x + w, y + h), (0, 0, 255), 2) # Red rectangle cv2.putText(overlay, "Red", (x, y - 10), cv2.FONT_HERSHEY_SIMPLEX, 0.6, (0, 0, 255), 2)

# Blue contours

contours, _ = cv2.findContours(mask_blue, cv2.RETR_EXTERNAL, cv2.CHAIN_APPROX_SIMPLE)
for cnt in contours:
if cv2.contourArea(cnt) > MIN_AREA:
x, y, w, h = cv2.boundingRect(cnt)
cv2.rectangle(overlay, (x, y), (x + w, y + h), (255, 0, 0), 2) # Blue rectangle cv2.putText(overlay, "Blue", (x, y - 10), cv2.FONT_HERSHEY_SIMPLEX, 0.6, (255, 0, 0), 2)

# Green contours

contours, _ = cv2.findContours(mask_green, cv2.RETR_EXTERNAL, cv2.CHAIN_APPROX_SIMPLE)
for cnt in contours:
if cv2.contourArea(cnt) > MIN_AREA:
x, y, w, h = cv2.boundingRect(cnt)
cv2.rectangle(overlay, (x, y), (x + w, y + h), (0, 255, 0), 2) # Green rectangle cv2.putText(overlay, "Green", (x, y - 10), cv2.FONT_HERSHEY_SIMPLEX, 0.6, (0, 255, 0), 2)

# Show original and overlay side by side

combined = np.hstack((frame, overlay))
cv2.imshow("Color Detection", combined)

if cv2.waitKey(1) & 0xFF == ord('q'): break

finally:
picam2.stop()
cv2.destroyAllWindows()

## Conclusion

The Raspberry Pi camera, combined with HSV thresholding and contour detection, can successfully detect Red, Blue, and Green objects. Using tuned HSV ranges and disabling automatic white balance ensures that colors are detected accurately. Minimum contour filtering removes noise, and rectangles with labels provide a clear visualization of detected objects. This system can be adapted for real-time applications, robotics, and color-based tracking.

I can also add a diagram showing the detection pipeline (camera → HSV → mask → contours → overlay) if you want, to make the report visually complete.

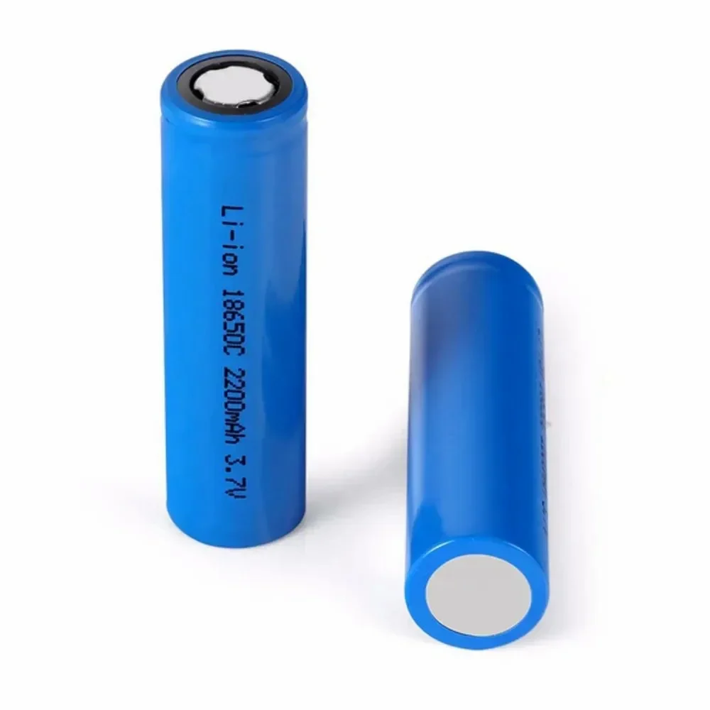
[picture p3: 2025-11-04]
schemes/Lithium Battery.webp

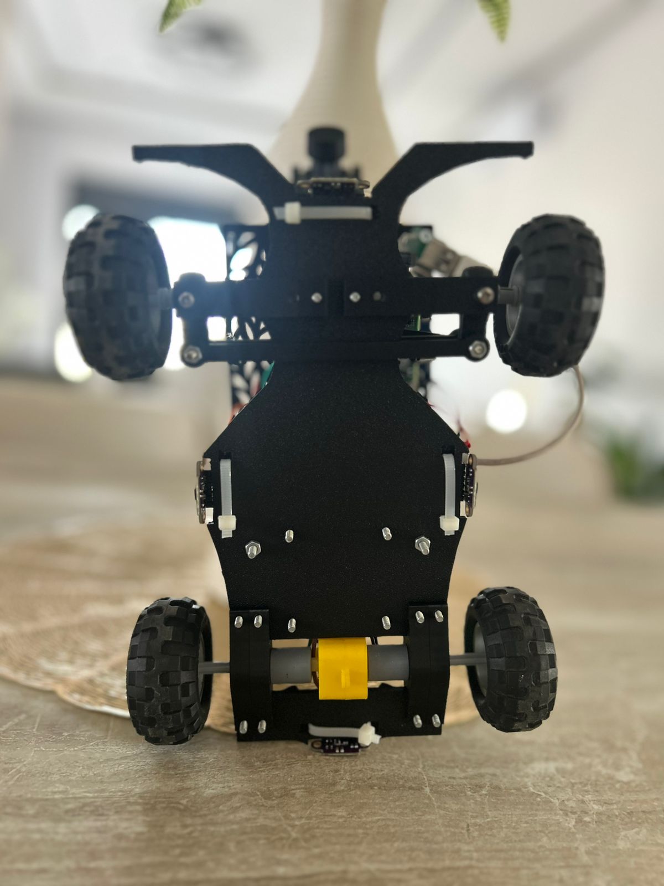
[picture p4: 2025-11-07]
v-photos/bottom.jpg

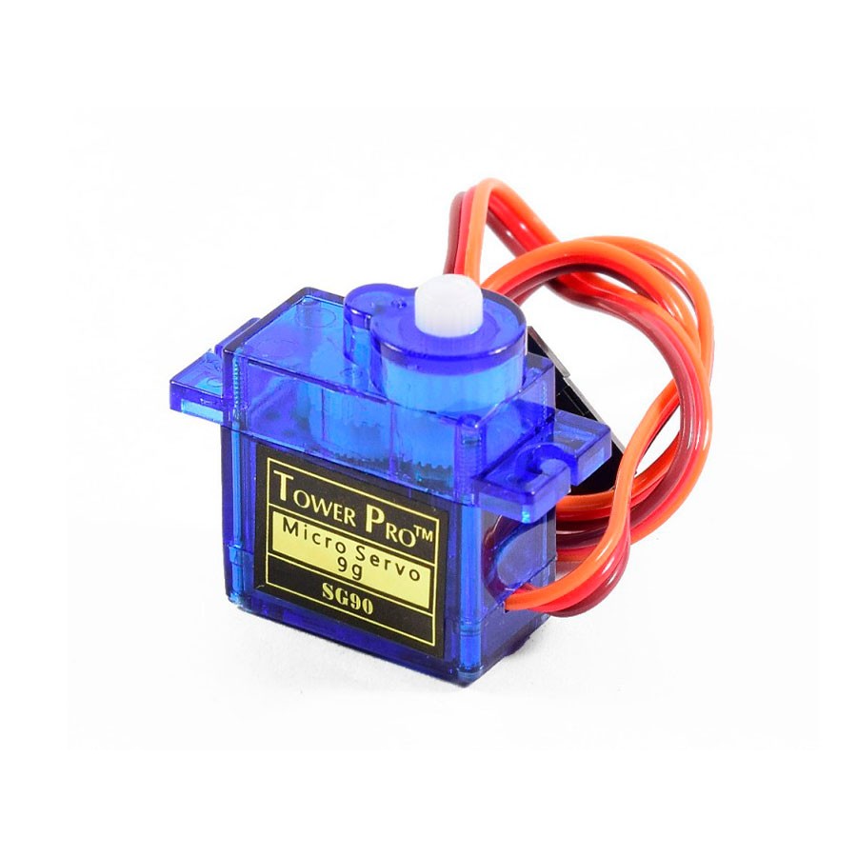
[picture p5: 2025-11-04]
schemes/Micro Servo.jpg

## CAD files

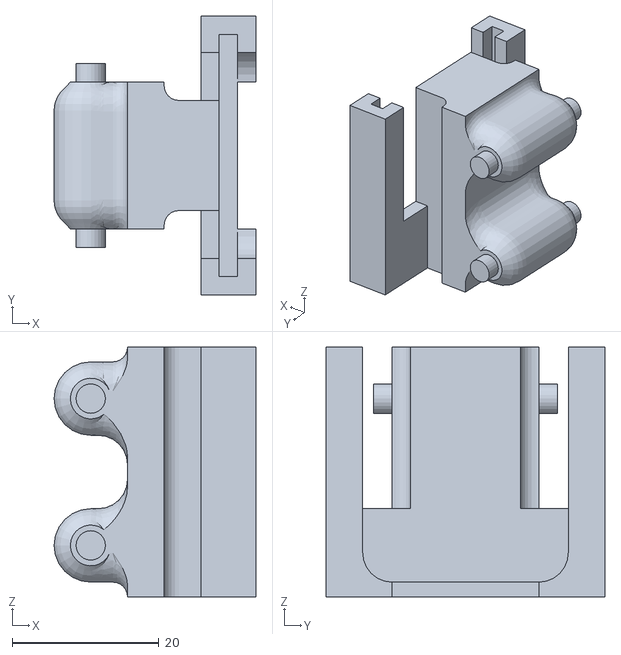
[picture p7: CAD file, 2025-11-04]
models/cameraMount1.stl
27.5 x 38.0 x 34.0

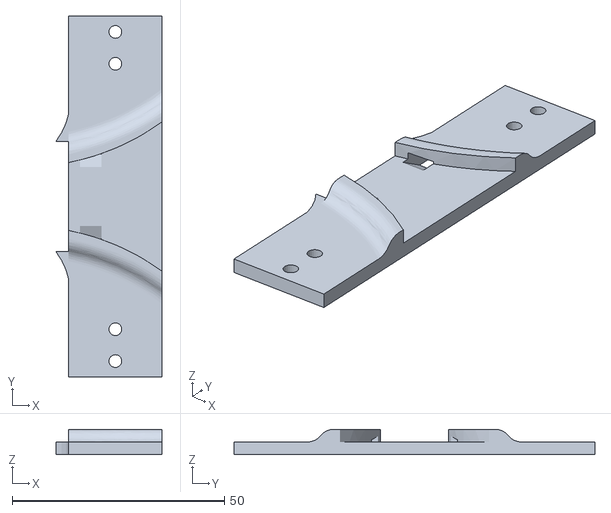
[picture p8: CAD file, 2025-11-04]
models/BaseSmall.stl
25.0 x 85.0 x 6.00

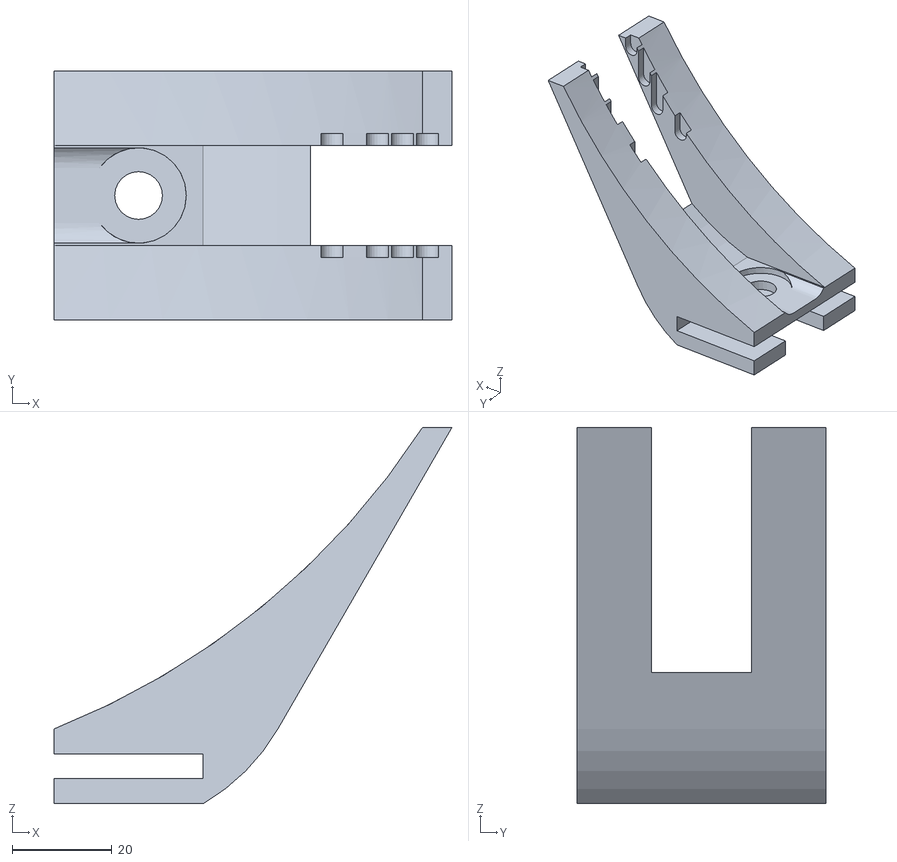
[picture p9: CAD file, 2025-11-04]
models/cameraMount2.stl
80.0 x 50.0 x 75.6

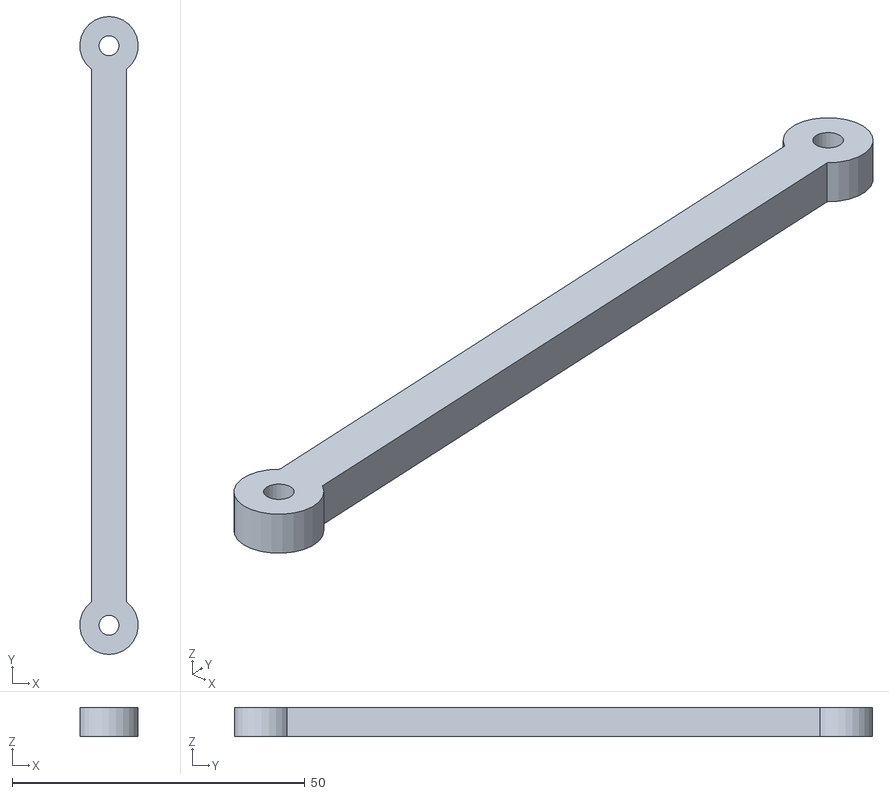
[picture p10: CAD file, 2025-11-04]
models/steeringAxle.stl
9.97 x 109.0 x 5.00

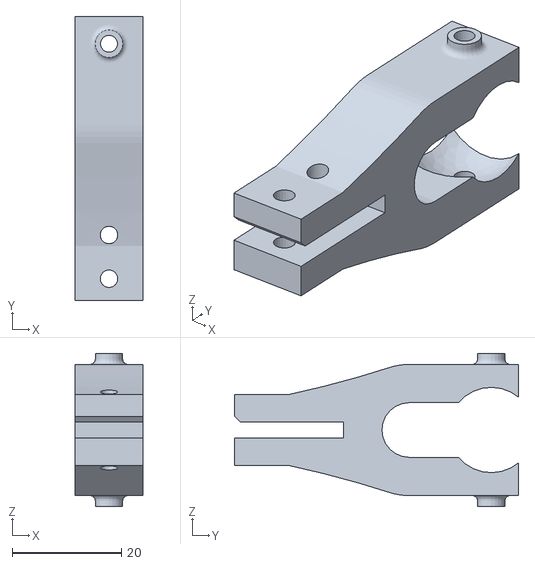
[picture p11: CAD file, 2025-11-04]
models/clipper.stl
12.5 x 52.0 x 28.0

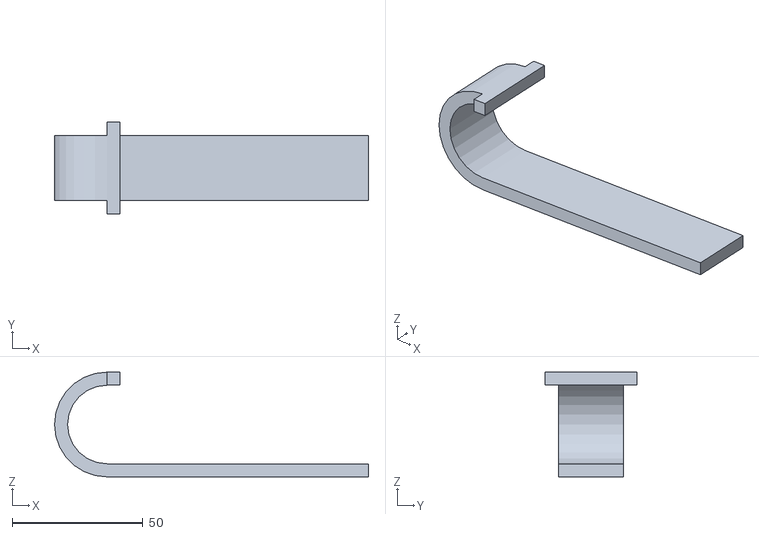
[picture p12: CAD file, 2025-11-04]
models/raspHolder.stl
120.0 x 35.0 x 40.0

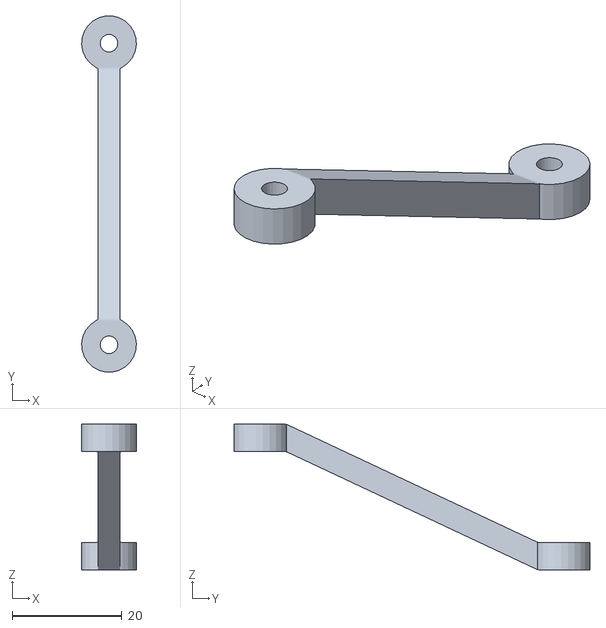
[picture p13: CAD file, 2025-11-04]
models/steeringRotator.stl
9.98 x 64.9 x 26.5

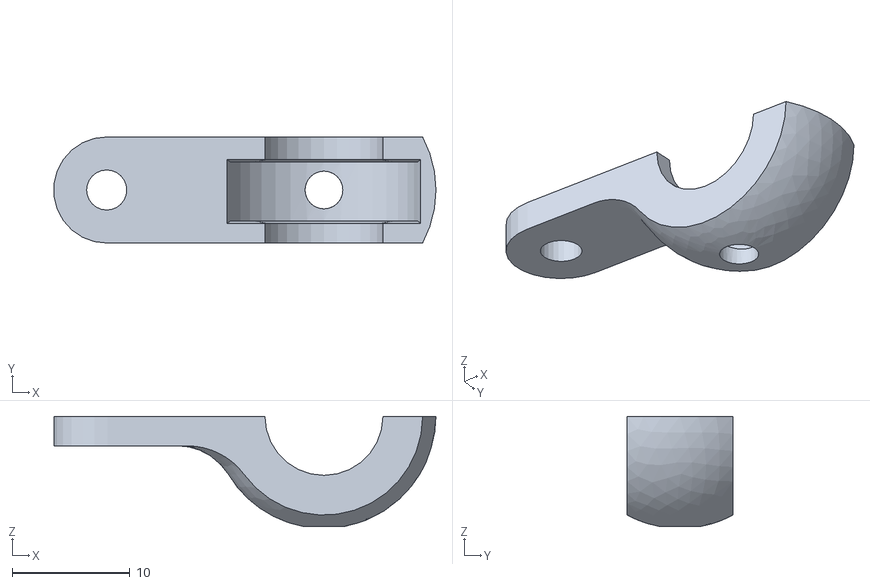
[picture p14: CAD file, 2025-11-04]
models/steering.stl
32.4 x 9.00 x 9.35

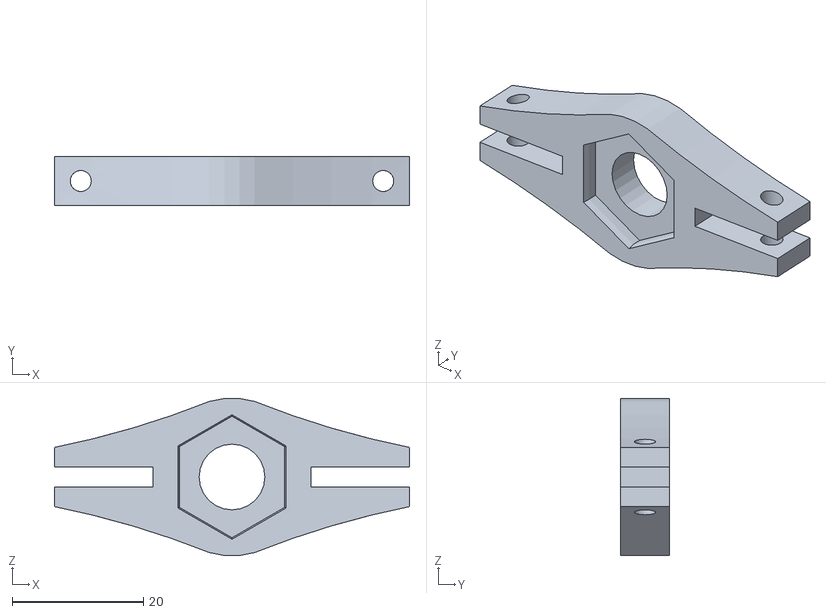
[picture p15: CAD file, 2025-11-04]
models/backChassis.stl
54.0 x 7.50 x 23.9

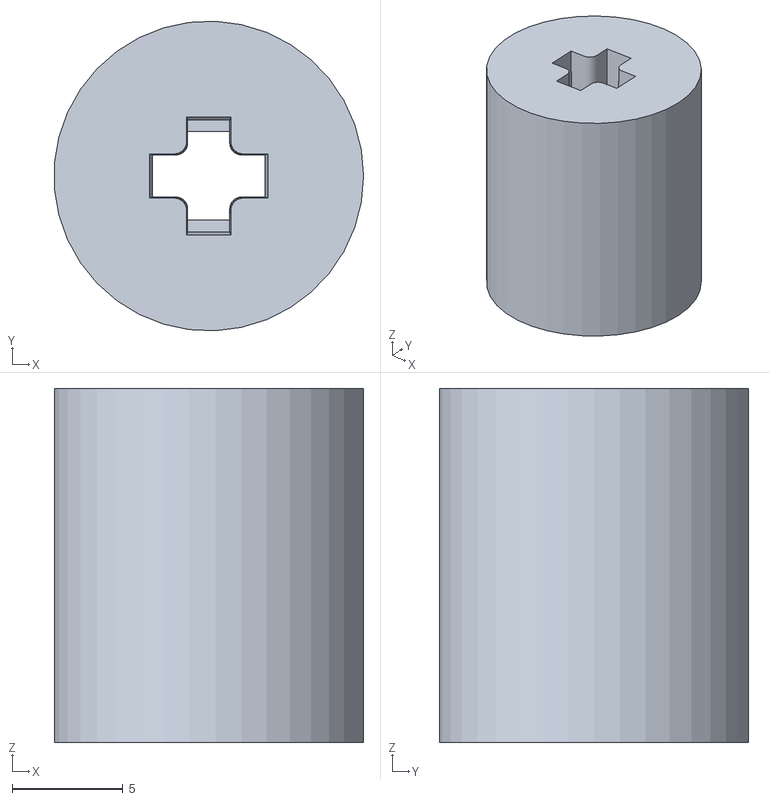
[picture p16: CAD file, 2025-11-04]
models/backChassisTight.stl
14.0 x 14.0 x 16.0

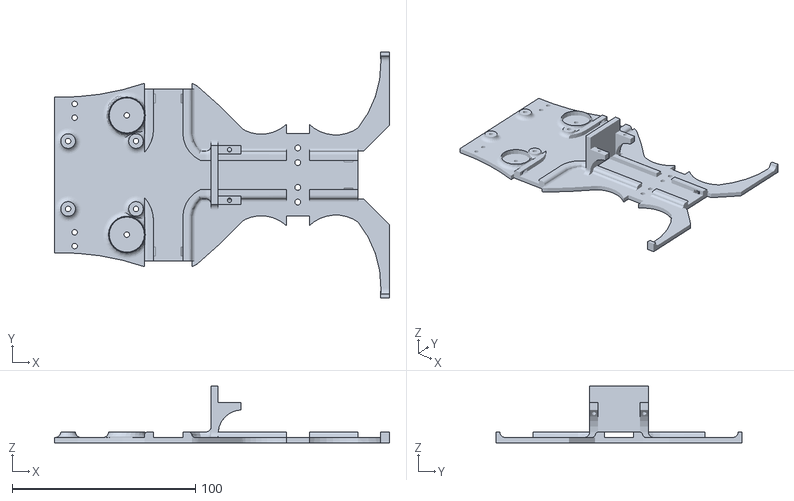
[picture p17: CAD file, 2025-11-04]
models/BaseBig.stl
182.7 x 134.3 x 31.0

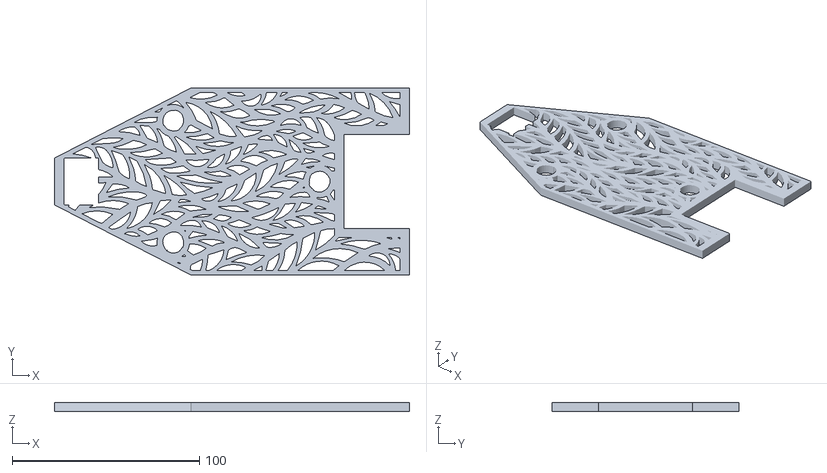
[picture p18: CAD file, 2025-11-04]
models/BaseTop.stl
189.5 x 100.0 x 5.01

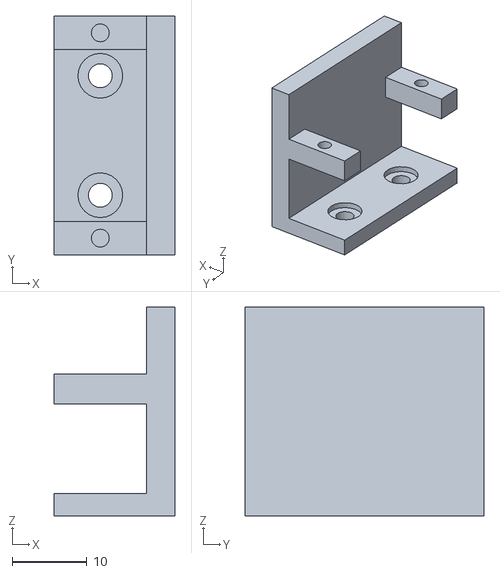
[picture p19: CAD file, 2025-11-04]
models/servoMount.stl
16.2 x 32.0 x 28.0

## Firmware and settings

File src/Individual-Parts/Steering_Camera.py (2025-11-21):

from flask import Flask, Response, render_template_string, request, jsonify
from picamera2 import Picamera2
import cv2
import time
import json
import threading
import numpy as np
import math
import board
import adafruit_mpu6050
import pigpio
from gpiozero import AngularServo, Device
from gpiozero.pins.pigpio import PiGPIOFactory

app = Flask(__name__)

# -----------------------------
# Hardware Pin Configuration
# -----------------------------
SERVO_PIN = 18
IN1, IN2, ENA = 24, 23, 13

# Servo limits
SERVO_MAX_RIGHT = 35
SERVO_MAX_LEFT = -35

# Motor settings
DEFAULT_MOTOR_SPEED = 220

# PID Controller parameters
KP = 0.8
KI = 0.01
KD = 0.3

# Direction settings
SERVO_DIRECTION = 1
GYRO_DIRECTION = -1

# -----------------------------
# Camera Setup
# -----------------------------
picam2 = Picamera2()
preview_config = picam2.create_preview_configuration(main={"size": (640, 480)})
picam2.configure(preview_config)
picam2.start()
time.sleep(2)

# -----------------------------
# Steering State Controller (Vision-based target calculation)
# -----------------------------
class VisionSteeringController:
    def __init__(self):
        self.target_angle = 0.0  # Current target heading (accumulated)
        self.max_rate = 2.0      # Maximum degrees per frame to change
        self.deadzone = 1000     # Ignore small differences (noise reduction)
        self.k_integral = 0.01   # How fast to accumulate angle
        self.lock = threading.Lock()
        self.is_active = False   # Only accumulate when active
        self.lap_limit = 1080.0  # Stop after 3 laps (3 × 360°)
        self.lap_min = 1070.0    # Minimum threshold
        self.lap_max = 1090.0    # Maximum threshold
        
    def update(self, left_pixels, right_pixels):
        """
        Update target angle based on wall pixel difference
        More left pixels = turn right (increase angle)
        More right pixels = turn left (decrease angle)
        Only updates if active (after START clicked)
        """
        with self.lock:
            if not self.is_active:
                # Don't update target angle until started
                return self.target_angle, 0.0, 0
            
            difference = left_pixels - right_pixels
            
            # Apply deadzone to ignore small differences
            if abs(difference) < self.deadzone:
                difference = 0
            
            # Calculate rate of change (angular velocity)
            rate = difference * self.k_integral
            
            # Clamp rate to prevent sudden jumps
            rate = max(-self.max_rate, min(self.max_rate, rate))
            
            # Accumulate the angle (integral control)
            self.target_angle += rate
            
            return self.target_angle, rate, difference
    
    def get_target_angle(self):
        with self.lock:
            return self.target_angle
    
    def should_stop(self, current_rotation):
        """Check if robot should stop based on lap completion"""
        with self.lock:
            return self.is_active and (self.lap_min <= abs(current_rotation) <= self.lap_max)
    
    def start(self):
        """Activate vision steering"""
        with self.lock:
            self.is_active = True
    
    def stop(self):
        """Deactivate vision steering"""
        with self.lock:
            self.is_active = False
    
    def reset(self):
        """Reset to initial heading"""
        with self.lock:
            self.target_angle = 0.0
            self.is_active = False
    
    def set_angle(self, angle):
        """Manually set target angle"""
        with self.lock:
            self.target_angle = angle
    
    def set_k_integral(self, value):
        with self.lock:
            self.k_integral = value
    
    def set_max_rate(self, value):
        with self.lock:
            self.max_rate = value
    
    def set_deadzone(self, value):
        with self.lock:
            self.deadzone = value
    
    def set_lap_limit(self, degrees):
        """Set the rotation limit for auto-stop"""
        with self.lock:
            self.lap_limit = degrees
            self.lap_min = degrees - 10
            self.lap_max = degrees + 10

# -----------------------------
# Gyroscope Steering Controller (Hardware control)
# -----------------------------
class GyroSteeringController:
    def __init__(self):
        # Initialize pigpio for motors
        self.pi = pigpio.pi()
        if not self.pi.connected:
            raise RuntimeError("pigpio daemon not running. Run 'sudo pigpiod' first")
        
        for p in (ENA, IN1, IN2):
            self.pi.set_mode(p, pigpio.OUTPUT)
        
        self.pi.set_PWM_frequency(ENA, 2000)
        
        # Initialize servo
        Device.pin_factory = PiGPIOFactory()
        self.servo = AngularServo(
            SERVO_PIN,
            min_angle=SERVO_MAX_LEFT,
            max_angle=SERVO_MAX_RIGHT,
            min_pulse_width=0.0012,
            max_pulse_width=0.0017
        )
        
        # Initialize MPU6050
        i2c = board.I2C()
        self.mpu = adafruit_mpu6050.MPU6050(i2c)
        
        # State variables
        self.current_heading = 0.0
        self.cumulative_rotation = 0.0  # Tracks total rotation (no limits)
        self.target_heading = 0.0
        self.last_time = time.time()
        self.integral = 0.0
        self.last_error = 0.0
        self.is_moving = False
        self.current_speed = DEFAULT_MOTOR_SPEED
        self.current_servo_angle = 0.0
        self.running = False
        self.lock = threading.Lock()
        
        # Raw gyro data
        self.gyro_x = 0.0
        self.gyro_y = 0.0
        self.gyro_z = 0.0
        
        # Calibrate gyro
        self.calibrate_gyro()
        
    def calibrate_gyro(self, samples=100):
        print("Calibrating gyroscope...")
        gyro_z_offset = 0.0
        for i in range(samples):
            gyro_z_offset += self.mpu.gyro[2]
            time.sleep(0.01)
        self.gyro_z_offset = gyro_z_offset / samples
        print(f"Gyro calibrated. Offset: {self.gyro_z_offset:.4f}")
    
    def run_motor(self, speed):
        forward = speed >= 0
        self.pi.write(IN1, 1 if forward else 0)
        self.pi.write(IN2, 0 if forward else 1)
        speed_value = min(255, abs(int(speed)))
        self.pi.set_PWM_dutycycle(ENA, speed_value)
        self.is_moving = True
        self.current_speed = speed_value
        
    def stop_motor(self):
        self.pi.set_PWM_dutycycle(ENA, 0)
        self.pi.write(IN1, 0)
        self.pi.write(IN2, 0)
        self.is_moving = False
        self.current_speed = 0
        
    def update_heading(self):
        current_time = time.time()
        dt = current_time - self.last_time
        self.last_time = current_time
        
        # Read raw gyro data
        gyro_data = self.mpu.gyro
        self.gyro_x = gyro_data[0]
        self.gyro_y = gyro_data[1]
        self.gyro_z = gyro_data[2]
        
        gyro_z_corrected = (self.gyro_z - self.gyro_z_offset) * GYRO_DIRECTION
        heading_change = math.degrees(gyro_z_corrected * dt)
        
        with self.lock:
            # Update both heading (normalized) and cumulative rotation (unlimited)
            self.cumulative_rotation += heading_change
            self.current_heading = (self.current_heading + heading_change + 180) % 360 - 180
        
    def calculate_steering_angle(self, target_heading):
        with self.lock:
            # Calculate error based on cumulative rotation (no normalization for vision tracking)
            error = target_heading - self.cumulative_rotation
        
        # Note: We don't normalize the error here because vision target is cumulative
        # This allows the robot to track continuous rotation beyond ±180°
            
        self.integral += error
        self.integral = max(min(self.integral, 100), -100)
        
        derivative = error - self.last_error
        self.last_error = error
        
        steering = (KP * error + KI * self.integral + KD * derivative) * SERVO_DIRECTION
        steering = max(min(steering, SERVO_MAX_RIGHT), SERVO_MAX_LEFT)
        
        return steering, error
    
    def get_current_heading(self):
        with self.lock:
            return self.current_heading
    
    def get_gyro_data(self):
        """Return raw gyro rotation rates and both heading types"""
        with self.lock:
            return {
                'x': self.gyro_x,
                'y': self.gyro_y, 
                'z': self.gyro_z,
                'heading': self.current_heading,
                'cumulative': self.cumulative_rotation
            }
    
    def set_target_heading(self, heading):
        with self.lock:
            self.target_heading = heading
            self.integral = 0.0
            self.last_error = 0.0
        
    def start_continuous_steering(self, speed=DEFAULT_MOTOR_SPEED):
        """Start continuous steering mode"""
        self.running = True
        self.run_motor(speed)
        
    def stop_continuous_steering(self):
        """Stop continuous steering mode"""
        self.running = False
        self.stop_motor()
        self.servo.angle = 0
        self.current_servo_angle = 0
        
    def steering_loop(self, vision_controller):
        """Main steering loop - runs continuously"""
        print("Starting steering loop...")
        self.last_time = time.time()
        
        while self.running:
            # Update current heading from gyro
            self.update_heading()
            
            # Check if we should auto-stop after completing laps
            # Check GYRO cumulative rotation, not vision target
            with self.lock:
                current_rotation = self.cumulative_rotation
            
            if vision_controller.should_stop(current_rotation):
                print(f"\n🏁 3 laps completed! Gyro cumulative rotation: {current_rotation:.1f}°")
                self.stop_continuous_steering()
                vision_controller.stop()
                break
            
            # Get target heading from vision controller
            target = vision_controller.get_target_angle()
            self.set_target_heading(target)
            
            # Calculate and apply steering
            steering_angle, error = self.calculate_steering_angle(target)
            self.servo.angle = steering_angle
            self.current_servo_angle = steering_angle
            
            time.sleep(0.02)  # 50Hz update rate
            
    def cleanup(self):
        self.stop_motor()
        self.servo.angle = 0
        self.servo.close()
        self.pi.stop()

# Global controllers
vision_steering = VisionSteeringController()
gyro_steering = GyroSteeringController()
steering_thread = None

# -----------------------------
# ROI Configuration
# -----------------------------
def load_roi_config(path="roi_config.json"):
    try:
        with open(path, "r") as f:
            cfg = json.load(f)
        print("✓ Loaded ROI config")
        return cfg["zones"]
    except:
        print("⚠ Using default ROI config")
        return {
            "Corner_Top": 20,
            "Corner_Bottom": 40,
            "ignore_Top": 20,
            "Corner_LM": 0,
            "Corner_RM": 100,
            "Right_Wall_Top": 40,
            "Left_Wall_Top": 30,
            "Wall_Bottom": 70,
            "Right_Wall_RM": 100,
            "Right_Wall_LM": 70,
            "Left_Wall_RM": 30,
            "Left_Wall_LM": 0,
        }

# Color detection for walls
COLOR_LOW  = (0, 0, 0)      # lower HSV bound (black walls)
COLOR_HIGH = (180, 255, 60)  # upper HSV bound

# -----------------------------
# Video Stream Generator
# -----------------------------
def gen_frames():
    zones = load_roi_config()

    while True:
        frame = picam2.capture_array()
        frame = cv2.cvtColor(frame, cv2.COLOR_RGB2BGR)
        hsv = cv2.cvtColor(frame, cv2.COLOR_BGR2HSV)

        h, w, _ = frame.shape

        # ---- ROI pixel boundaries ----
        Ct = int(h * zones["Corner_Top"] / 100)
        Cb = int(h * zones["Corner_Bottom"] / 100)
        RWt = int(h * zones["Right_Wall_Top"] / 100)
        LWt = int(h * zones["Left_Wall_Top"] / 100)
        Wb = int(h * zones["Wall_Bottom"] / 100)

        Clm = int(w * zones["Corner_LM"] / 100)
        Crm = int(w * zones["Corner_RM"] / 100)
        Rlm = int(w * zones["Right_Wall_LM"] / 100)
        Rrm = int(w * zones["Right_Wall_RM"] / 100)
        Llm = int(w * zones["Left_Wall_LM"] / 100)
        Lrm = int(w * zones["Left_Wall_RM"] / 100)

        # ------------------- Pixel Counting ---------------------
        mask = cv2.inRange(hsv, COLOR_LOW, COLOR_HIGH)

        # Extract ROIs
        corner_roi = mask[Ct:Cb, Clm:Crm]
        left_roi   = mask[LWt:Wb, Llm:Lrm]
        right_roi  = mask[RWt:Wb, Rlm:Rrm]

        # Count pixels
        corner_pixels = cv2.countNonZero(corner_roi)
        left_pixels   = cv2.countNonZero(left_roi)
        right_pixels  = cv2.countNonZero(right_roi)

        # ------------------- UPDATE TARGET HEADING -------------------
        target_angle, rate, difference = vision_steering.update(left_pixels, right_pixels)
        current_heading = gyro_steering.get_current_heading()
        gyro_data = gyro_steering.get_gyro_data()

        # ---------------- DRAW ROI boxes ------------------------
        cv2.rectangle(frame, (Clm, Ct), (Crm, Cb), (0, 255, 0), 2)      # Corner
        cv2.rectangle(frame, (Llm, LWt), (Lrm, Wb), (255, 0, 0), 2)      # Left
        cv2.rectangle(frame, (Rlm, RWt), (Rrm, Wb), (0, 0, 255), 2)      # Right

        # ---- Draw pixel count text on each ROI ----
        cv2.putText(frame, f"C:{corner_pixels}",
                    (Clm, Ct - 10), cv2.FONT_HERSHEY_SIMPLEX,
                    0.5, (0,255,0), 2)

        cv2.putText(frame, f"L:{left_pixels}",
                    (Llm, LWt - 10), cv2.FONT_HERSHEY_SIMPLEX,
                    0.5, (255,0,0), 2)

        cv2.putText(frame, f"R:{right_pixels}",
                    (Rlm, RWt - 10), cv2.FONT_HERSHEY_SIMPLEX,
                    0.5, (0,0,255), 2)

        # ------------------- Display Steering Info -------------------
        info_y = 30
        line_height = 25
        
        # Left column - Vision data
        cv2.putText(frame, "VISION TARGET", (10, info_y), 
                    cv2.FONT_HERSHEY_SIMPLEX, 0.6, (0, 255, 255), 2)
        cv2.putText(frame, f"Target: {target_angle:.1f}°",
                    (10, info_y + line_height), cv2.FONT_HERSHEY_SIMPLEX,
                    0.6, (0, 255, 255), 2)
        cv2.putText(frame, f"Rate: {rate:.2f}°/f",
                    (10, info_y + line_height * 2), cv2.FONT_HERSHEY_SIMPLEX,
                    0.5, (255, 255, 255), 1)
        cv2.putText(frame, f"Diff: {difference}px",
                    (10, info_y + line_height * 3), cv2.FONT_HERSHEY_SIMPLEX,
                    0.5, (255, 255, 255), 1)
        
        # Right column - Gyro data
        right_x = w - 280
        cv2.putText(frame, "GYRO ACTUAL", (right_x, info_y), 
                    cv2.FONT_HERSHEY_SIMPLEX, 0.6, (255, 255, 0), 2)
        cv2.putText(frame, f"Cumulative: {gyro_data['cumulative']:.1f}°",
                    (right_x, info_y + line_height), cv2.FONT_HERSHEY_SIMPLEX,
                    0.6, (255, 255, 0), 2)
        cv2.putText(frame, f"Heading: {current_heading:.1f}°",
                    (right_x, info_y + line_height * 2), cv2.FONT_HERSHEY_SIMPLEX,
                    0.5, (200, 200, 200), 1)
        cv2.putText(frame, f"Gyro Z: {gyro_data['z']:.3f}",
                    (right_x, info_y + line_height * 3), cv2.FONT_HERSHEY_SIMPLEX,
                    0.5, (255, 255, 255), 1)
        
        # Bottom - Motor status and lap progress
        bottom_y = h - 80
        
        # Calculate lap progress
        laps_completed = abs(gyro_data['cumulative']) / 360.0
        lap_percentage = (abs(gyro_data['cumulative']) / 1080.0) * 100.0
        lap_percentage = min(lap_percentage, 100.0)
        
        cv2.putText(frame, f"Motor: {gyro_steering.current_speed}/255 | Servo: {gyro_steering.current_servo_angle:.1f}° | Laps: {laps_completed:.2f}/3",
                    (10, bottom_y), cv2.FONT_HERSHEY_SIMPLEX,
                    0.6, (255, 255, 255), 2)
        
        # Lap progress bar
        bar_width = 300
        bar_height = 20
        bar_x = 10
        bar_y = bottom_y + 10
        
        # Background bar
        cv2.rectangle(frame, (bar_x, bar_y), (bar_x + bar_width, bar_y + bar_height), (50, 50, 50), -1)
        
        # Progress bar (changes color as it fills)
        progress_width = int(bar_width * (lap_percentage / 100.0))
        if lap_percentage < 33:
            color = (0, 255, 0)  # Green for first lap
        elif lap_percentage < 66:
            color = (0, 255, 255)  # Yellow for second lap
        else:
            color = (0, 165, 255)  # Orange for third lap
        
        cv2.rectangle(frame, (bar_x, bar_y), (bar_x + progress_width, bar_y + bar_height), color, -1)
        cv2.rectangle(frame, (bar_x, bar_y), (bar_x + bar_width, bar_y + bar_height), (255, 255, 255), 2)
        
        # Progress text
        cv2.putText(frame, f"{lap_percentage:.1f}%", (bar_x + bar_width + 10, bar_y + 15), 
                    cv2.FONT_HERSHEY_SIMPLEX, 0.5, (255, 255, 255), 2)
        
        # Visual indicator of target and current heading
        center_x = w // 2
        indicator_y = h - 40
        arrow_length = 50
        
        # Draw compass circle
        cv2.circle(frame, (center_x, indicator_y), 60, (100, 100, 100), 2)
        
        # Draw target heading (cyan arrow) - based on cumulative rotation
        target_normalized = target_angle % 360
        arrow_angle_rad = target_normalized * 3.14159 / 180
        end_x = int(center_x + arrow_length * np.sin(arrow_angle_rad))
        end_y = int(indicator_y - arrow_length * np.cos(arrow_angle_rad))
        cv2.arrowedLine(frame, (center_x, indicator_y), (end_x, end_y), 
                       (0, 255, 255), 4, tipLength=0.3)
        cv2.putText(frame, "T", (end_x + 5, end_y + 5), 
                    cv2.FONT_HERSHEY_SIMPLEX, 0.5, (0, 255, 255), 2)
        
        # Draw current heading (yellow arrow) - normalized display
        current_angle_rad = current_heading * 3.14159 / 180
        end_x2 = int(center_x + (arrow_length - 5) * np.sin(current_angle_rad))
        end_y2 = int(indicator_y - (arrow_length - 5) * np.cos(current_angle_rad))
        cv2.arrowedLine(frame, (center_x, indicator_y), (end_x2, end_y2), 
                       (0, 255, 255), 3, tipLength=0.3)
        cv2.putText(frame, "A", (end_x2 + 5, end_y2 + 5), 
                    cv2.FONT_HERSHEY_SIMPLEX, 0.5, (0, 255, 255), 2)
        
        # Draw center reference line (0° - North)
        cv2.line(frame, (center_x, indicator_y - 65), 
                (center_x, indicator_y - 52), (0, 255, 0), 2)
        cv2.putText(frame, "N", (center_x - 8, indicator_y - 68), 
                    cv2.FONT_HERSHEY_SIMPLEX, 0.5, (0, 255, 0), 2)
        
        # Status indicator
        status_color = (0, 255, 0) if gyro_steering.is_moving else (0, 0, 255)
        status_text = "RUNNING" if gyro_steering.is_moving else "STOPPED"
        cv2.circle(frame, (w - 80, 30), 12, status_color, -1)
        cv2.putText(frame, status_text, (w - 150, 35), 
                    cv2.FONT_HERSHEY_SIMPLEX, 0.6, status_color, 2)

        # Encode frame to JPEG
        ret, buffer = cv2.imencode(".jpg", frame)
        if not ret:
            continue

        yield (b'--frame\r\n'
               b'Content-Type: image/jpeg\r\n\r\n' + buffer.tobytes() + b'\r\n')
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

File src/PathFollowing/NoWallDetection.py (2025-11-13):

"""
Simple Corner Detection + Gyro Turns ONLY
No wall following - just detect corners and turn 90° precisely
"""

import time
import board
from digitalio import DigitalInOut
from adafruit_vl53l0x import VL53L0X
import adafruit_mpu6050
import pigpio
import RPi.GPIO as GPIO
from gpiozero import AngularServo, Device
from gpiozero.pins.pigpio import PiGPIOFactory

# ============================================================================
# HARDWARE PINS
# ============================================================================
IN1, IN2, ENA = 24, 23, 13
SERVO_PIN = 18
SWITCH_PIN = 25
LED_BLUE = 6

XSHUT_PINS = [board.D22, board.D27, board.D17, board.D26]  # Right, Left, Back, Front
SENSOR_NAMES = ['Right', 'Left', 'Back', 'Front']

# ============================================================================
# TUNING
# ============================================================================
SPEED = 220

# ============================================================================
# MEDIAN FILTER
# ============================================================================
class MedianFilter:
    """Keep last N readings and return median to filter out spikes"""
    def __init__(self, window_size=5):
        self.window_size = window_size
        self.readings = {}
    
    def update(self, sensor_name, value):
        """Add new reading and return filtered value"""
        if sensor_name not in self.readings:
            self.readings[sensor_name] = []
        
        self.readings[sensor_name].append(value)
        
        if len(self.readings[sensor_name]) > self.window_size:
            self.readings[sensor_name].pop(0)
        
        sorted_vals = sorted(self.readings[sensor_name])
        return sorted_vals[len(sorted_vals) // 2]

sensor_filter = MedianFilter(window_size=5)

# ============================================================================
# SETUP
# ============================================================================
def setup_sensors():
    """Initialize TOF sensors"""
    print("Setting up sensors...")
    i2c = board.I2C()
    
    xshut = [DigitalInOut(pin) for pin in XSHUT_PINS]
    for p in xshut:
        p.switch_to_output(value=False)
    time.sleep(0.1)
    
    vl53 = []
    for i, p in enumerate(xshut):
        p.value = True
        time.sleep(0.2)
        sensor = VL53L0X(i2c)
        if i < len(xshut) - 1:
            sensor.set_address(i + 0x30)
        vl53.append(sensor)
    
    print("✓ Sensors ready")
    return vl53

def setup_motor_servo():
    """Initialize motor and servo"""
    pi = pigpio.pi()
    if not pi.connected:
        raise RuntimeError("pigpio daemon not running")
    
    for p in (IN1, IN2, ENA):
        pi.set_mode(p, pigpio.OUTPUT)
    pi.set_PWM_frequency(ENA, 2000)
    
    GPIO.setmode(GPIO.BCM)
    GPIO.setup(SWITCH_PIN, GPIO.IN, pull_up_down=GPIO.PUD_UP)
    GPIO.setup(LED_BLUE, GPIO.OUT)
    GPIO.output(LED_BLUE, GPIO.LOW)
    
    Device.pin_factory = PiGPIOFactory()
    servo = AngularServo(SERVO_PIN, min_pulse_width=0.0006, max_pulse_width=0.0023)
    servo.angle = 0
    
    print("✓ Motor & servo ready")
    return pi, servo

def setup_mpu6050():
    """Initialize gyro"""
    try:
        i2c = board.I2C()
        mpu = adafruit_mpu6050.MPU6050(i2c)
        print("✓ Gyro ready")
        return mpu
    except:
        print("⚠️  No gyro found - cannot run without gyro!")
        return None

# ============================================================================
# MOTOR CONTROL
# ============================================================================
def run_motor(pi, speed):
    pi.write(IN1, 1)
    pi.write(IN2, 0)
    pi.set_PWM_dutycycle(ENA, speed)

def stop_motor(pi):
    pi.set_PWM_dutycycle(ENA, 0)
    pi.write(IN1, 1)
    pi.write(IN2, 1)

# ============================================================================
# SENSOR READING WITH FILTERING
# ============================================================================
def read_sensors(vl53):
    """Read all 4 sensors with median filtering"""
    distances = {}
    for i, sensor in enumerate(vl53):
        name = SENSOR_NAMES[i]
        try:
            raw = sensor.range
            if 10 <= raw <= 1500:
                filtered = sensor_filter.update(name, raw)
                distances[name] = filtered
            else:
                distances[name] = 1500
        except:
            distances[name] = 1500
        time.sleep(0.1)
    return distances

# ============================================================================
# CORNER DETECTION
# ============================================================================
def detect_corner(distances):
    """
    Detect corner using filtered sensor data
    Returns: 'left', 'right', or None
    """
    r, l, f = distances['Right'], distances['Left'], distances['Front']
    
    # Corner: front wall close AND one side clearly open
    if f < 200:
        if l > 600 and r < 350:
            print(f"  → Corner LEFT detected (L={l}, R={r}, F={f})")
            return 'left'
        elif r > 600 and l < 350:
            print(f"  → Corner RIGHT detected (L={l}, R={r}, F={f})")
            return 'right'
    
    return None
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

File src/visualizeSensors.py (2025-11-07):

# SPDX-FileCopyrightText: 2021 ladyada for Adafruit Industries
# SPDX-License-Identifier: MIT
"""
Example of how to use the adafruit_vl53l0x library to change the assigned address of
multiple VL53L0X sensors on the same I2C bus. This example only focuses on 2 VL53L0X
sensors, but can be modified for more. BE AWARE: a multitude of sensors may require
more current than the on-board 3V regulator can output (typical current consumption during
active range readings is about 19 mA per sensor).
"""
import time
import board
from digitalio import DigitalInOut
from adafruit_vl53l0x import VL53L0X
import os

# declare the singleton variable for the default I2C bus
i2c = board.I2C()  # uses board.SCL and board.SDA
# i2c = board.STEMMA_I2C()  # For using the built-in STEMMA QT connector on a microcontroller

# declare the digital output pins connected to the "SHDN" pin on each VL53L0X sensor
xshut = [
    DigitalInOut(board.D22), # GPIO 22
    DigitalInOut(board.D27), # GPIO 27
    DigitalInOut(board.D17), # GPIO 17
    DigitalInOut(board.D26), # GPIO 26
    # add more VL53L0X sensors by defining their SHDN pins here
]

for power_pin in xshut:
    # make sure these pins are a digital output, not a digital input
    power_pin.switch_to_output(value=False)
    print(f"shut down sensor{power_pin}")
    # These pins are active when Low, meaning:
    #   if the output signal is LOW, then the VL53L0X sensor is off.
    #   if the output signal is HIGH, then the VL53L0X sensor is on.

# all VL53L0X sensors are now off

# initialize a list to be used for the array of VL53L0X sensors
vl53 = []

# Names for the sensors in the same order as xshut
SENSOR_NAMES = ['Right', 'Left','Back',  'Front']

# now change the addresses of the VL53L0X sensors
for i, power_pin in enumerate(xshut):
    # turn on the VL53L0X to allow hardware check
    power_pin.value = True
    print(f"turned ON sensor{power_pin}")
    # instantiate the VL53L0X sensor on the I2C bus & insert it into the "vl53" list
    vl53.insert(i, VL53L0X(i2c))  # also performs VL53L0X hardware check
    # no need to change the address of the last VL53L0X sensor
    if i < len(xshut) - 1:
        # default address is 0x29. Change that to something else
        vl53[i].set_address(i + 0x30)  # address assigned should NOT be already in use

# there is a helpful list of pre-designated I2C addresses for various I2C devices at
# https://learn.adafruit.com/i2c-addresses/the-list
# According to this list 0x30-0x34 are available, although the list may be incomplete.

def clear_screen():
    """Clear the terminal screen"""
    os.system('clear' if os.name == 'posix' else 'cls')

def draw_car_with_distances(distances_dict):
    """
    Draw a car representation with distance readings on each side
    distances_dict should have keys: 'Front', 'Back', 'Left', 'Right'
    """
    clear_screen()
    
    front = distances_dict.get('Front', '---')
    back = distances_dict.get('Back', '---')
    left = distances_dict.get('Left', '---')
    right = distances_dict.get('Right', '---')
    
    # Create the car ASCII art with distances
    print("\n")
    print(f"                  {front:^10}")
    print("                ┌──────────┐")
    print("                │  FRONT   │")
    print("              ┌─┴──────────┴─┐")
    print(f"  {left:<10}  │              │  {right:>10}")
    print(f"              │      🚗       │")
    print(f"  LEFT        │              │        RIGHT")
    print("              └─┬──────────┬─┘")
    print("                │   BACK   │")
    print("                └──────────┘")
    print(f"                  {back:^10}")
    print("\n")
    print("Press Ctrl+C to stop")

def detect_range():
    """continuously read and display sensor ranges"""
    try:
        while True:
            distances_dict = {}
            
            for index, sensor in enumerate(vl53):
                try:
                    distance = sensor.range
                    distances_dict[SENSOR_NAMES[index]] = f"{distance}mm"
                except OSError:
                    distances_dict[SENSOR_NAMES[index]] = "ERROR"
                time.sleep(0.05)
            
            draw_car_with_distances(distances_dict)
            time.sleep(0.05)
            
    except KeyboardInterrupt:
        print("\n\nStopping sensor readings...")

print(
    "Multiple VL53L0X sensors' addresses are assigned properly\n"
    "Starting car visualization with distance readings..."
)
time.sleep(2)
detect_range()

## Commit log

2025-11-04 Added all STL files
    [BaseBig.stl, BaseSmall.stl, BaseTop.stl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]
2025-11-07 Add path following logic with VL53L0X sensors
    Implement a simple VL53L0X TOF path following algorithm using multiple sensors and motor control.
2025-11-07 Add VL53L0X TOF Path Following Guide
    Add comprehensive path following guide for VL53L0X TOF sensor, detailing navigation strategies, versions, tuning parameters, common issues, and performance comparisons.
2025-11-11 Add camera streaming with Flask and Tailwind
2025-11-13 Add corner detection and gyro-controlled turning
    Implement a corner detection and gyro-based turning system for a robot. The system uses TOF sensors for corner detection and allows for both progressive and fixed angle turning methods.
    [NoWallDetection.py]
2025-11-15 Implement Flask server for video and sensor data streaming
    Added Flask streaming server for live video feed and sensor data display.
2025-11-17 Add GyroSteering class for servo control
    Implement gyro-based steering control system with PID.
2025-11-17 Refactor gyro steering implementation and motor control
    Refactor gyro steering logic, improve motor control, and enhance code structure.
2025-11-18 Add camera-based navigation system for WRO
    Implement WRO navigation system using camera vision for wall and line detection.
2025-11-19 Integrate Flask for live camera streaming
    Refactor camera ROI configurator to integrate Flask for web streaming and update ROI loading mechanism.
2025-11-19 Implement gyroscope steering and update frontend
    Added gyroscope-based steering control to manage target angle based on wall pixel differences. Enhanced frontend with controls for steering parameters and actions.
2025-11-19 Adjust max_rate and deadzone parameters in cameraROI
2025-11-20 Add Flask app for vision and gyro steering control
    This file implements a Flask application for integrated vision and gyroscope steering control, including hardware setup, steering controllers, video streaming, and a web interface.
2025-11-20 Adjust motor speed and PID parameters
2025-11-20 Refactor steering camera settings and logic
    Updated motor speed and PID parameters for improved performance. Adjusted maximum rate and deadzone for steering control, and modified cumulative rotation handling.
2025-11-20 Adjust servo limits and improve heading calculations
2025-11-20 Adjust servo limits and motor speed settings
2025-11-20 Fix print statement formatting in cleanup section
2025-11-20 Adjust parameters for steering camera control
2025-11-21 Implement lap limit and update UI for steering
    Added lap limit functionality and updated UI elements to reflect changes in the vision steering controller.
2025-11-21 Adjust servo limits and update ROI calculations
2025-11-21 Add autonomous wall-following robot implementation
    Implement autonomous wall-following robot with vision and gyro control. Includes camera setup, steering controllers, and button activation for mission start.
2025-11-21 Refactor button handling to use switch monitoring
    Updated button handling to use switch monitoring instead of button press events. Added mission state tracking for toggle switch.
